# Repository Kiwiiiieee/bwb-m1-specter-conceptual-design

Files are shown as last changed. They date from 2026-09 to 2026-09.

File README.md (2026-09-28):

# BWB-M1 "Specter": Conceptual Design of a Supersonic Strike Fighter

*Team of 3 · AE 405 Aircraft Design · Izmir University of Economics · Spring 2026*

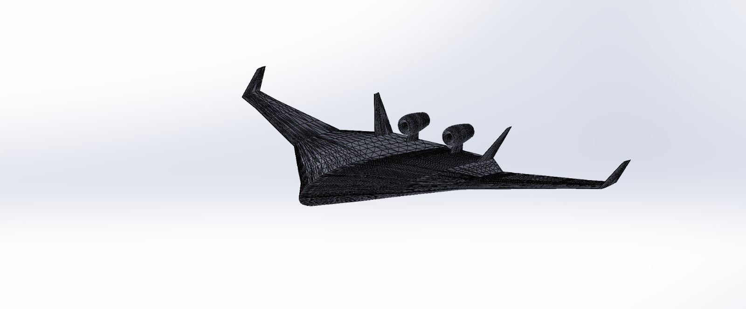
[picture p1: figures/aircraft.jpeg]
BWB-M1 Specter 3D model


## Engineering question
Can a blended wing body (BWB), adapted from the Boeing X-48 geometry, meet the requirements of a two-seat supersonic strike fighter: Mach 2.0 maximum speed, a 14 deg/s sustained turn rate, a 12.2 km service ceiling and the design mission range?

## Approach
First-order conceptual design following **Raymer's semi-empirical conceptual design method** (*Aircraft Design: A Conceptual Approach*, 6th ed.), with the rubber-engine approach:

- **Mission analysis and fuel fractions:** 13-segment combat strike mission (about 1,000 nm ground range); segment weight fractions from Raymer's fixed historical values or the Breguet range/endurance equations.
- **Takeoff weight sizing:** fixed-point iteration of Raymer's sizing equation, using the jet-fighter empty-weight regression with a composite correction K<sub>comp</sub> = 0.95.
- **Wing geometry:** X-48 planform adapted (leading-edge sweep increased from 47° to 58°, outer-panel t/c = 0.04 with a NACA 64A-204 airfoil, twin all-moving vertical stabilizers, dorsal engine pods).
- **Propulsion:** two GE F110-GE-132 class afterburning turbofans (144.6 kN AB thrust each).
- **Aerodynamics:** Raymer component drag buildup for C<sub>D0</sub>, induced-drag factor and maximum L/D.
- **Performance:** takeoff, climb and specific excess power, service ceiling, maximum speed (Ackeret thin-wing wave drag with an empirical body correction), sustained turn rate, and a T/W vs W/S constraint diagram.
- **Weight breakdown:** Raymer statistical group weights for jet fighters.
- **Geometry and model:** an online Boeing X-48 STL model was adapted in SolidWorks (engines resized, vertical stabilizers added, surfaces cleaned, rescaled) and prepared for 3D printing.

## Results
| Parameter | Computed | Requirement | Status |
|:--|:--|:--|:--|
| Mission range (internal fuel) | 1,000 nm | 1,000 nm | Met |
| Maximum speed (level flight) | Below M 2.0 (wave-drag failure) | M 2.0 | **Not met** |
| Sustained turn rate (M 0.9, 6,100 m) | 14.5 deg/s | 14 deg/s | Met |
| Service ceiling | Far above 12,200 m | 12,200 m | Met |

Other key figures from the report:
- Fuel-fraction product W<sub>ff</sub> = 0.686; fuel fraction W<sub>f</sub>/W<sub>0</sub> = 0.333.
- Maximum takeoff weight W<sub>0</sub> = 14,963 kg (32,988 lb); empty-weight fraction 0.575.
- C<sub>D0</sub> = 0.00813 and (L/D)<sub>max</sub> = 17.0 at subsonic cruise (M 0.85), a direct benefit of the large BWB planform.
- T/W = 1.97 with afterburner at MTOW; stall speed about 40 kt.

**Why Mach 2.0 fails.** At M 2.0 and 12,200 m, wave drag on the thick X-48 centre body gives an estimated drag of about 808 kN against about 141 kN of available afterburner thrust, a shortfall of roughly a factor of five. The X-48 geometry was optimised for Mach 0.85 transport flight, so this is a basic mismatch between the chosen configuration and a Mach-2 mission. The report also flags an unusually low wing loading (38.9 kg/m²) caused by the transport-scale planform. It suggests these fixes: a centre body thinner than t/c 0.06 with Whitcomb area ruling, a smaller planform, redefining the requirement as a dive-limited top speed, or more installed thrust.

## Validation
The analysis uses no independent test data. The report puts its computed values in context by comparing them with operational aircraft (F-22A, F-16C, B-2, SR-71, Concorde). It also notes that the constraint diagram, which is based on steady level flight, does not capture the centre-body wave drag. That is why the Mach-2 failure only shows up in the detailed drag analysis.

## Figures
Figures are taken from the report (figure numbers and captions as in the report).

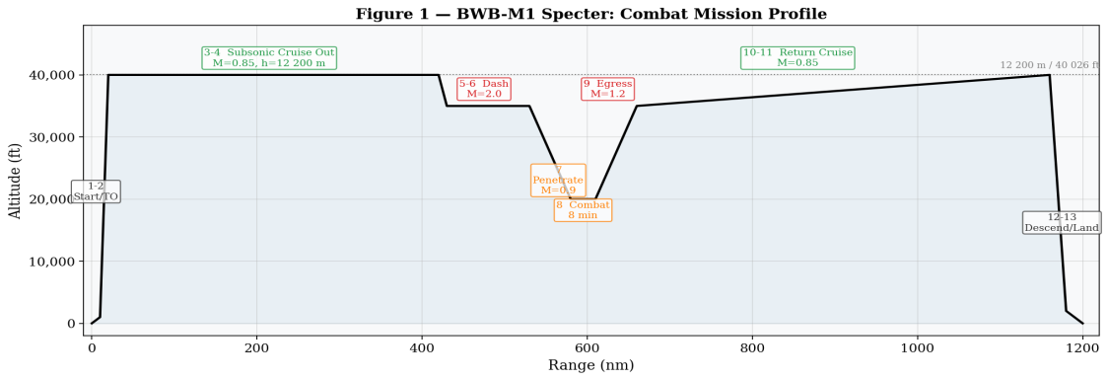
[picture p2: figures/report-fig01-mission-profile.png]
Mission profile

*Figure 1: BWB-M1 Specter, 13-segment combat mission profile. Altitude in ft, range in nm.*

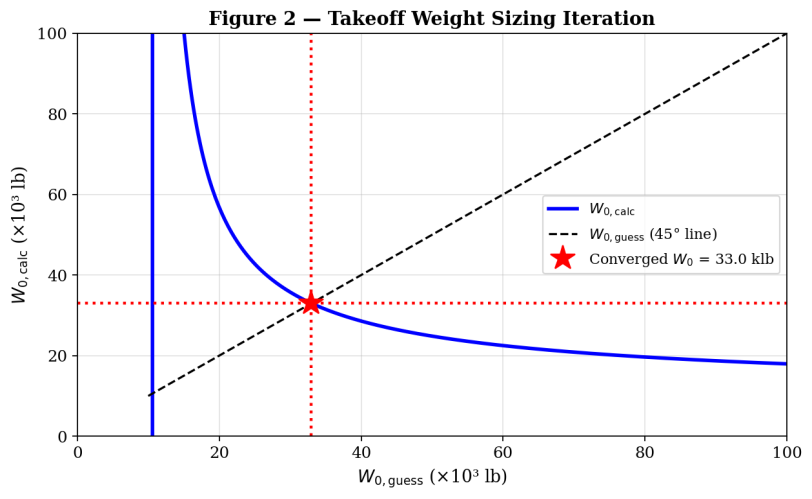
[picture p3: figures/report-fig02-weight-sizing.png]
Weight sizing

*Figure 2: Takeoff weight sizing iteration convergence. The intersection gives W<sub>0</sub> = 32,988 lb.*

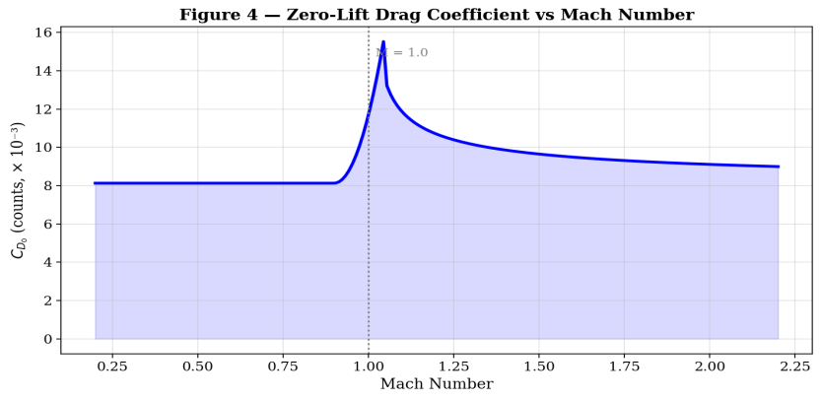
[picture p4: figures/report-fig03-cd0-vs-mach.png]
CD0 vs Mach

*Figure 3: Zero-lift drag coefficient C<sub>D0</sub> vs. Mach number.*

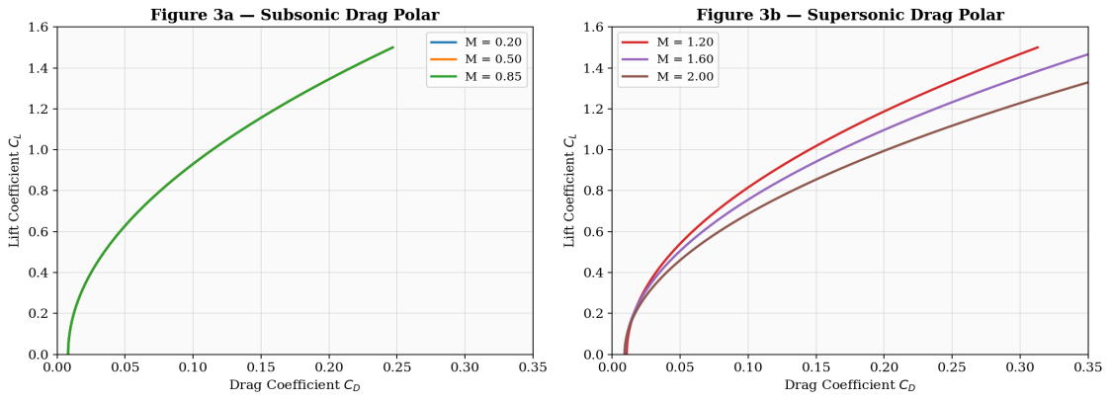
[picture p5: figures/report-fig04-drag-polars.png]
Drag polars

*Figure 4: Drag polars at subsonic (left) and supersonic (right) Mach numbers.*

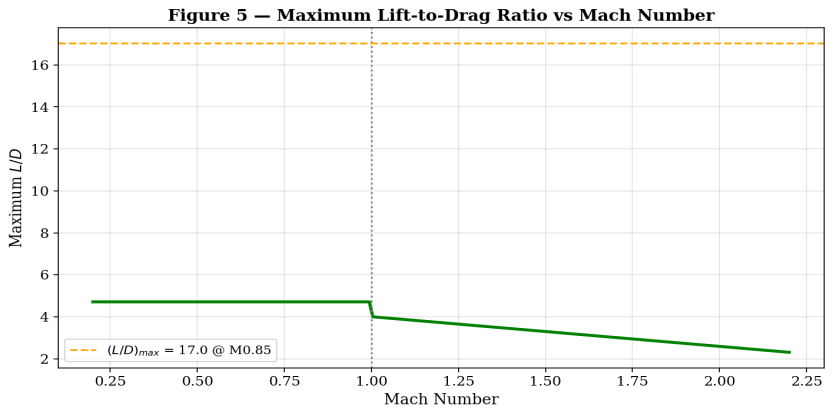
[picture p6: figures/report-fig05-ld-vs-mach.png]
L/D vs Mach

*Figure 5: Maximum L/D vs. Mach number. Subsonic efficiency is high; supersonic degradation is severe.*

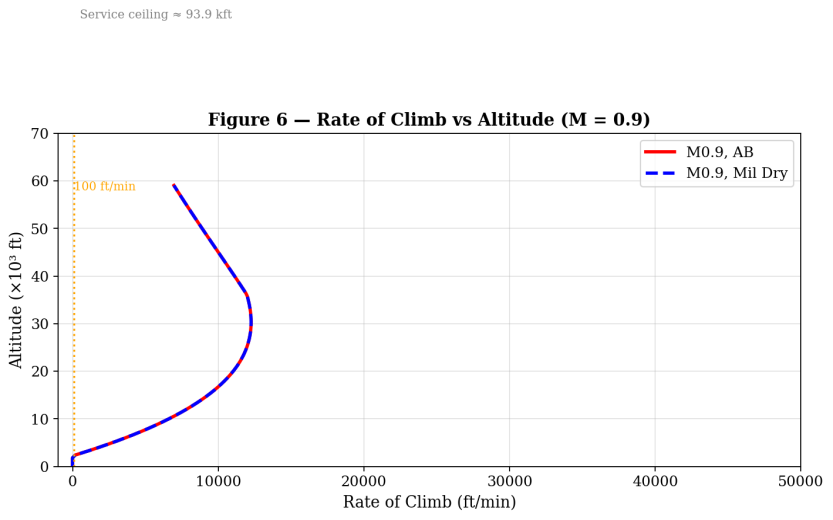
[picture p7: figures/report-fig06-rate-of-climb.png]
Rate of climb

*Figure 6: Rate of climb vs. altitude at M = 0.9, MTOW, with afterburner (solid) and dry power (dashed).*

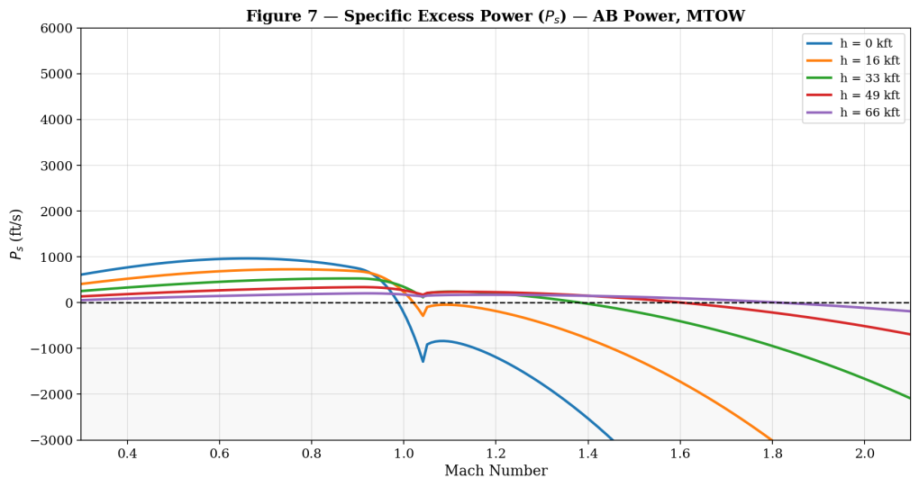
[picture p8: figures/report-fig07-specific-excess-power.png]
Specific excess power

*Figure 7: Specific excess power P<sub>s</sub> [ft/s] vs. Mach number at multiple altitudes, afterburner, MTOW.*

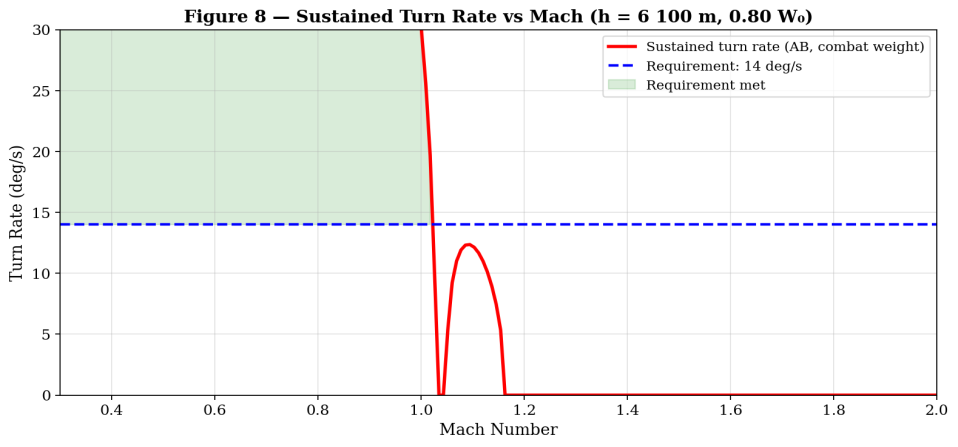
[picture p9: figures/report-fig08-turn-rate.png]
Turn rate

*Figure 8: Sustained turn rate vs. Mach number (h = 6,100 m, 0.80 W<sub>0</sub>, afterburner). The shaded region indicates compliance with the 14 deg/s requirement.*

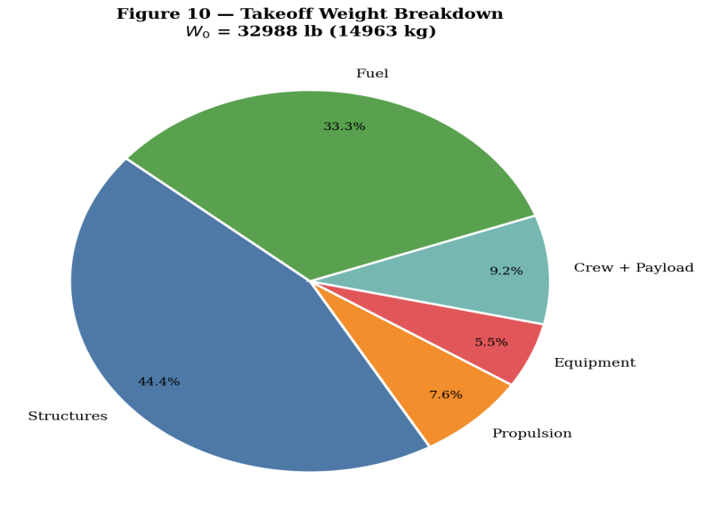
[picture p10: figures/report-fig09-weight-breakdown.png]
Weight breakdown

*Figure 9: Takeoff weight breakdown. W<sub>0</sub> = 14,963 kg.*

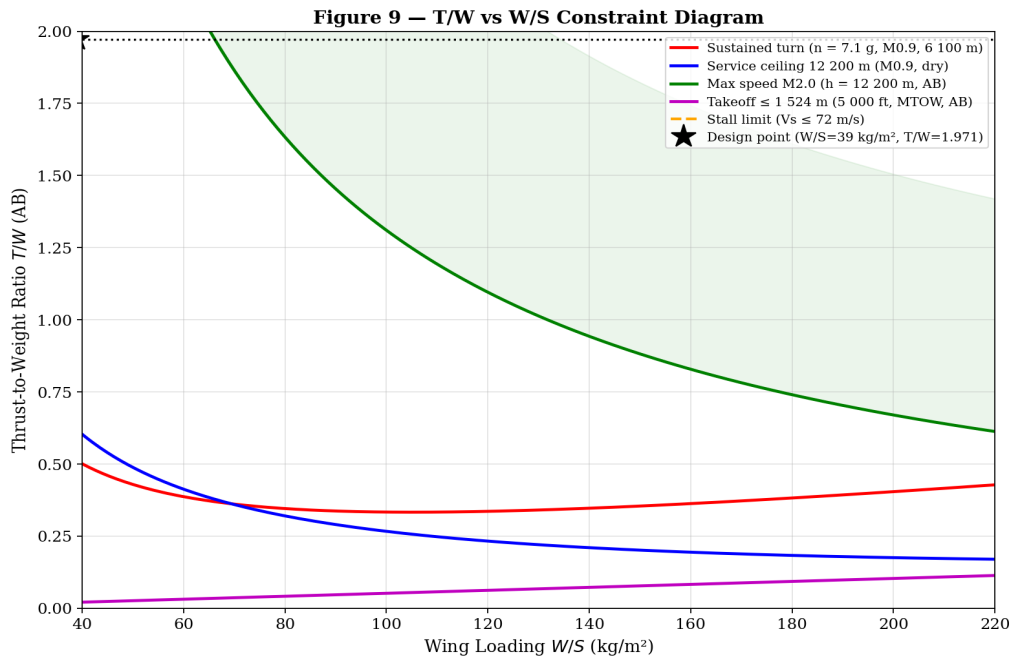
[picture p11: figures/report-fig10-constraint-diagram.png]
Constraint diagram

*Figure 10: T/W vs. W/S constraint diagram with the design point (star).*

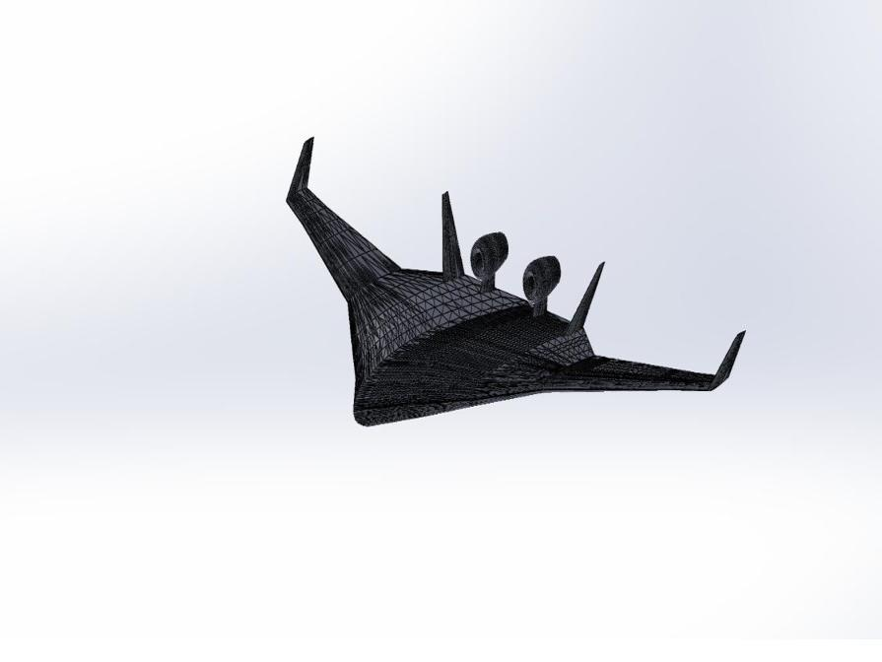
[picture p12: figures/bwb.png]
BWB model, second view

*3D model of the BWB-M1 Specter (modified Boeing X-48 geometry with twin dorsal engines and twin vertical stabilizers).*

## Repository contents
| Path | Content | Opens with |
|:--|:--|:--|
| `report/BWB_M1_Specter_Report.pdf` | Conceptual design report (20 pages) | Any PDF reader |
| `slides/AE405_Slides.pdf` | Presentation slides | Any PDF reader |
| `tools/cad/STL_File_Sergio_Jorge_Koutar_3dprint.STL` | STL model prepared for 3D printing | GitHub's STL viewer, SolidWorks, Blender, any slicer (e.g. Cura, PrusaSlicer) |
| `tools/cad/STL_File_Sergio_Jorge_Koutar_cfdanalysis.STL` | STL model prepared for CFD analysis | SolidWorks, Ansys SpaceClaim / Fluent meshing, Blender |
| `figures/` | 3D model renders and report figures | Image viewer |

## How to reproduce
No analysis code is included. All equations, inputs and intermediate values (mission-segment fractions, sizing iteration, drag buildup, performance calculations) are written out in the report, Sections 3–10, and follow Raymer (2018). The STL files can be opened directly for inspection, 3D printing or CFD meshing.

## Team and my contribution
Team of three: **Sergio San Juan Alonso**, **Jorge González Martínez** and **Kaoutar Ammara**. Instructor: Abbasali Saboktakin.

My sections:
- mission analysis and fuel fractions
- takeoff weight sizing
- wing geometry
- propulsion system
- aerodynamic analysis
- performance analysis
- weight breakdown

## References
Main references cited in the report: Raymer, *Aircraft Design: A Conceptual Approach*, 6th ed. (AIAA, 2018); Liebeck, "Design of the blended wing body subsonic transport", *Journal of Aircraft* 41(1), 2004; Boeing / NASA Dryden, X-48B/C BWB demonstrator program. The full list is in the report.

Kaoutar Ammara · Aerospace Engineer · [GitHub](https://github.com/Kiwiiiieee) · [LinkedIn](https://linkedin.com/in/kaoutar-ammara)

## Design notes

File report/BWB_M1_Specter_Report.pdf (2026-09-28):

AE 405 — Aircraft Design | Spring 2026 | BWB-M1 Specter | Conceptual Design Report

IZMIR UNIVERSITY OF ECONOMICS

Department of Aerospace Engineering

AE 405 - Aircraft Design | Spring 2026

Instructor: Abbasali Saboktakin

CONCEPTUAL DESIGN REPORT

AE 405 Project - Military Aircraft

## BWB-M1 "SPECTER"

Blended Wing Body Supersonic Strike Fighter

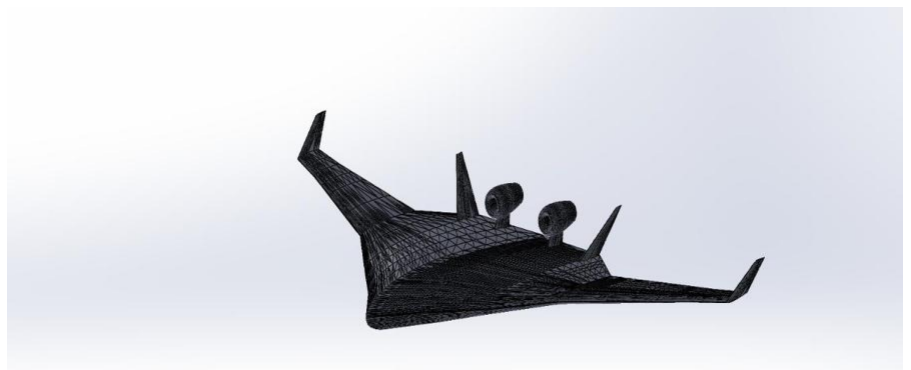
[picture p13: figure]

BWB-M1 "Specter" - 3D model. Modified Boeing X-48 geometry with twin dorsal engines and twin vertical

stabilizers.

Sergio San Juan Alonso (ID: 20250615902)

Jorge González Martínez (ID: 20250615901)

Kaoutar Ammara (ID: 20210615207)

May 2026

ABSTRACT

This report presents a first-order conceptual design of the BWB-M1 "Specter," a twin-engine

blended wing body (BWB) supersonic strike fighter adapted from the Boeing X-48 experimental

aircraft geometry. The design follows the systematic methodology of Raymer's Aircraft Design: A

Conceptual Approach (6th ed.), covering mission analysis, weight sizing, aerodynamic buildup,

propulsion selection, and performance verification against stated requirements.

A 13-segment mission yields a fuel-fraction product Wff = 0.686, and iterative sizing

converges to a maximum takeoff weight W₀ = 14,963 kg. The aerodynamic analysis gives Cᴰ₀ =

0.00813 and (L/D)ₘₐₓ = 17.0 at subsonic cruise — both a direct benefit of the large BWB planform.

Of the four primary performance requirements, three are satisfied: mission range (7,000 nm),

sustained turn rate (14.5 deg/s ≥ 14 deg/s), and service ceiling (far exceeded).

The Mach 2.0 maximum-speed requirement is not met. Wave drag on the thick BWB

center body exceeds available afterburner thrust at M = 2.0 in level flight at 12,200 m by a factor

of approximately five. This is a fundamental incompatibility between the subsonic X-48 geometry

and a Mach-2 mission and is reported transparently throughout this document.

TABLE OF CONTENTS

Abstract | 2
Table of Contents | 3
Nomenclature | 4
1. Introduction | 4
2. Conceptual Design Methodology | 5
3. Mission Analysis and Fuel Fractions | 6
4. Takeoff Weight Sizing | 8
5. Wing Geometry and Configuration | 9
6. Propulsion System | 10
7. Aerodynamic Analysis | 11
8. Performance Analysis | 12
8.1 Takeoff Performance | 12
8.2 Climb and Specific Excess Power | 13
8.3 Service Ceiling | 13
8.4 Maximum Speed — Requirement Not Met | 13
8.5 Sustained Turn Rate | 14
9. Weight Breakdown | 15
10. T/W vs W/S Constraint Diagram | 15
11. Stability and Control | 16
12. Design Deficiencies and Recommended Corrections | 15
13. Aircraft Arrangement Drawings | 17
14. Software Design | 18
15. Manufacturing Preparation | 19
16. Conclusion | 19
References | 20

NOMENCLATURE

A - Aspect ratio | L/D - Lift-to-drag ratio
b - Wingspan, m | M - Mach number
CD0 - Zero-lift drag coefficient | MAC - Mean aerodynamic chord, m
Cf - Skin friction coefficient | n - Load factor (g)
CL - Lift coefficient | q - Dynamic pressure, N/m²
Ct - Thrust specific fuel consumption, hr⁻¹ | R - Range, m (or nm)
e - Oswald efficiency factor | S - Planform area, m²
FF - Aerodynamic form factor | T - Engine thrust, N
K - Induced drag factor, 1/(πAe) | W0 - Takeoff gross weight, kg or lb
λ - Taper ratio, ct/cr | Wff - Mission fuel-fraction product
ΛLE - Leading-edge sweep angle | We - Empty weight, kg
ψ̇- Turn rate, deg/s | Wf - Fuel weight, kg

### 1. INTRODUCTION

The continuous growth of regional and long-range air transportation has created a strong demand

for new aircraft concepts capable of improving efficiency while increasing operational flexibility.

Modern militaries aim to operate from a wider network of regional airports, where runway lengths,

noise restrictions, and fuel consumption become decisive factors in the near future of aircraft

design. In this context, this project focuses on developing a conceptual aircraft configuration

manufactured to operate from regional hubs while still meeting the mission requirements imposed

in this task.

The aircraft is required to transport a payload of two passengers, including their equipment, with

an estimated total mass of 120 kg per passenger. Despite its small passenger capacity, the mission

demands a remarkable range of three thousand nautical miles and a maximum speed of Mach 2, a

14 degrees per second turn rate and a 12.2 kilometre service ceiling, positioning the design

challenge at the intersection between the maximum speed and the turn rate. These constraints

naturally motivate the exploration of non-conventional configurations capable of offering

enhanced aerodynamic efficiency, structural integration, and fuel volume capacity.

To address these challenges, a Blended-Wing-Body (BWB) layout is selected as the base

configuration. This architecture merges the wing and fuselage into a single lifting surface, reducing

the wetted area, improving lift-to-drag ratio, and providing great internal volume suitable for fuel

storage and pressurized cabins. BWBs have been extensively investigated as potential high-efficiency alternatives to traditional tube-and-wing aircraft (TAW), particularly for missions

requiring superior aerodynamic performance and long endurance.

The objective of this project is to perform the preliminary sizing, geometric definition, and

aerodynamic analysis of such a BWB aircraft concept. The design process includes establishing

the mission requirements, estimating weight and fuel fractions, defining the external geometry, and

evaluating the aerodynamic behaviour through computational tools as Ansys Fluent between

others. The resulting aircraft configuration must satisfy the payload and range requirements, cruise

performance targets, and operational constraints.

### 2. CONCEPTUAL DESIGN METHODOLOGY

The design follows the four-phase Raymer (2018) conceptual design sequence:

- Requirements analysis — translate Table 1 into aerodynamic and propulsion constraints

(T/W, W/S, L/D, M).

- Mission analysis and weight sizing (Ch. 3) — define a 13-segment mission, compute

per-segment fuel fractions via Breguet equations and historical fixed values, iterate the

gross-weight equation.

- Aerodynamic and propulsion sizing (Chs. 5, 12) — component drag buildup,

propulsion selection via a constraint diagram.

- Performance verification (Chs. 17, 19) — compute all required performance metrics;

report compliance or non-compliance explicitly.

The rubber-engine approach is used throughout. A composite-structure correction Kcomp

= 0.95 is applied to Raymer's empty-weight equation to account for the advanced composite BWB

airframe.

### 3. MISSION ANALYSIS AND FUEL FRACTIONS

The design mission is a 13-segment combat strike patrol with a total ground range of

approximately 1,000 nm. Figure 1 shows the mission altitude-range profile.


Figure 1: BWB-M1 Specter — 13-segment combat mission profile. Altitude in ft, range in nm.

Each segment weight fraction is computed from Raymer Table 3.2 (fixed values) or from

the Breguet range equation:

Wi / Wi−1 = exp[ − R × Ct / (V × L/D) ]

where R [m], Cₜ [s⁻¹], V [m/s]. The Breguet endurance equation is used for the loiter segment. Table

2 lists all 13 fractions.

# | Description | Method | Wi/Wi−1 | Wi/W₀

1 | Engine start, warm-up, taxi | Fixed | 0.990 | 0.990
2 | Takeoff | Fixed | 0.990 | 0.980
3 | Climb to 12,200 m, accelerate to M 0.85 | Fixed | 0.971 | 0.952
4 | Subsonic cruise out — 400 nm, M 0.85 | Breguet | 0.951 | 0.905
5 | Acceleration to M 2.0 (afterburner) | Fixed | 0.960 | 0.869
6 | Supersonic dash — 100 nm, M 2.0 | Breguet | 0.967 | 0.841
7 | Penetration — 50 nm, M 0.9, h = 6,100 m | Breguet | 0.983 | 0.827
8 | Combat — 8 min, afterburner turns | Fixed | 0.930 | 0.769
9 | Supersonic egress — 50 nm, M 1.2 | Breguet | 0.980 | 0.754
10 | Return cruise — 500 nm, M 0.85 | Breguet | 0.940 | 0.708
11 | Loiter 20 min, sea level (reserve) | Breguet end. | 0.983 | 0.696
12 | Descent | Fixed | 0.990 | 0.689
13 | Land | Fixed | 0.995 | 0.686
The mission fuel-fraction product is:

Wff = ∏(Wi / Wi−1) = 0.686

Applying Raymer's 6% reserve and trapped-fuel factor:

Wf / W₀ = 1.06 × (1 − Wff) = 1.06 × (1 − 0.686) = 0.333

### 4. TAKEOFF WEIGHT SIZING

The takeoff gross weight is found from Raymer's sizing equation:

W₀ = (Wcrew + Wpayload) / (1 − Wf/W₀ − We/W₀)

The payload group is Wcrew+payload = 3,040 lb (1,379 kg): two crew with equipment

(440 lb), air-to-air missiles and gun (1,900 lb), mission systems (700 lb). The empty-weight

fraction uses Raymer's jet-fighter regression (Table 3.1) with composite correction:

We/W₀ = Kcomp × Aew × W₀ᶜ = 0.95 × 2.34 × W₀⁻¹·¹³ (W₀ in lb)

The fixed-point iteration is shown in Figure 2 and converges to the values in Table 3.

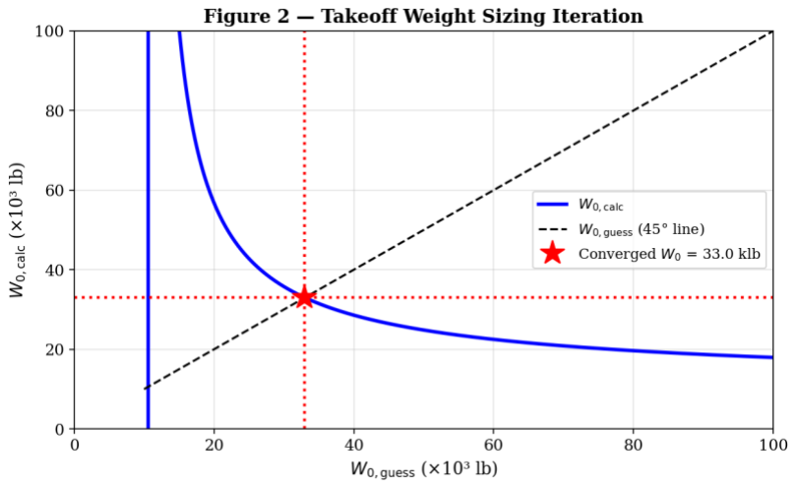
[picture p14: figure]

Figure 2: Takeoff weight sizing iteration convergence. Intersection gives W₀ = 32,988 lb.

Component | lb | kg | × W₀
Takeoff gross weight W₀ | 32,988 | 14,963 | 1.000
Empty weight We | 18,963 | 8,602 | 0.575
Fuel weight Wf | 10,985 | 4,983 | 0.333
Crew + payload + weapons | 3,040 | 1,379 | 0.092
Wing loading W/S | — | 38.9 kg/m² | —

The wing loading W/S = 38.9 kg/m² is anomalously low for a Mach-2 aircraft (F-22A: 375

kg/m²; B-2 Spirit flying wing: 109 kg/m²). This arises because the X-48 geometry was sized for a

much heavier transport and has a planform area S = 384.4 m² far exceeding what a two-seat fighter

mission requires. The consequences — very low stall speeds, excellent turn capability, but high

supersonic wave drag — are quantified in Section 8.

### 5. WING GEOMETRY AND CONFIGURATION

The blended wing body integrates the fuselage, center body, and outer wing panels into a

single continuous lifting surface, eliminating the non-lifting wetted area of a conventional fuselage.

The Boeing X-48 program demonstrated that BWB designs achieve 15–20% fuel-burn reductions

at subsonic cruise relative to tube-and-wing aircraft (Liebeck 2004). For the Specter, the X-48

geometry is adapted by: (i) increasing leading-edge sweep from 47° to 58°; (ii) reducing average

airfoil thickness to t/c = 0.04 on outer panels; (iii) adding twin all-moving vertical stabilizers; and

(iv) repositioning engines to dorsal pods.

Parameter | Symbol | Value | Units
Wingspan | b | 37.5 | m
Overall length | L | 18.5 | m
Root chord | cr | 18.5 | m
Tip chord | ct | 2.0 | m
Taper ratio | λ = ct/cr | 0.108 | —
Planform area | S | 384.4 | m²
Aspect ratio | A = b²/S | 3.66 | —
Mean aerodynamic chord | MAC | 12.46 | m
Leading-edge sweep | ΛLE | 58.0 | deg
Quarter-chord sweep | Λc/4 | 54.1 | deg
Avg. thickness ratio | t/c | 0.04 | —

The mean aerodynamic chord follows from:

MAC = (2/3) × cr × (1 + λ + λ²)/(1 + λ) = (2/3) × 18.5 × 1.120/1.108 = 12.46 m

The leading-edge normal Mach number at M = 2.0 is M⊥ = 2.0 × cos 58° = 1.06 —

consistent with the design practice of the SR-71 (ΛLE = 60°) and Concorde (ΛLE = 72°). The

outer wing panels use a NACA 64A-204 airfoil (t/c = 0.04, sharp leading edge). The center body

operates at t/c ≈ 0.08–0.12 for structural depth; this is the dominant source of supersonic wave

drag, discussed in Section 8.4.

### 6. PROPULSION SYSTEM

Two GE F110-GE-132 class afterburning turbofan engines are selected. The F110-GE-132

(powering the F-16 Block 60) provides the highest thrust in the F110 family at moderate engine

weight. Engines are mounted in dorsal over-wing pods fed by bifurcated S-duct inlets with

variable-area intake ramps for M = 0 to M = 2.0 operation.

Parameter | Value | Units
Engine | GE F110-GE-132 class | —
Number | 2 | —
AB thrust, each | 144.6 kN (32,500 lbf) | —
Dry (MIL) thrust, each | 86.7 kN (19,500 lbf) | —
Total AB thrust | 289.2 kN | N
Total dry thrust | 173.4 kN | N
T/W at MTOW (AB) | 1.97 | —
T/W at MTOW (dry) | 1.18 | —
TSFC, subsonic cruise (M 0.85) | ≈ 0.82 | hr⁻¹
TSFC, supersonic (M 2.0, AB) | ≈ 1.90 | hr⁻¹

The installed T/W = 1.97 (AB) is high relative to operational fighters (F-22: 1.22; F-16C:

1.10) because the aircraft is relatively light (W₀ = 14,963 kg) while carrying two full-size

augmented turbofans. This high thrust-to-weight ratio enables the sustained turn and climb

performance, and partially compensates for the supersonic wave drag — though not fully, as shown

in Section 8.4.

### 7. AERODYNAMIC ANALYSIS

The zero-lift parasite drag is estimated using Raymer's component buildup method (Ch.

12):

CD0 = (1/Sref) × Σ [ Cf × FF × Q × Swet ]i + ΔCD,misc

At design cruise (M = 0.85, h = 12,200 m, ReMAC = 6.62 × 10⁷):

Component | Cf | FF | Q | Swet/Sref | ΔCD₀
BWB wing-body (integrated) | 0.00212 | 1.177 | 1.00 | 2.20 | 0.00548
Vertical stabilizers (×2) | 0.00238 | 1.100 | 1.04 | 0.116 | 0.00023

Engine nacelles (×2) | 0.00240 | 1.180 | 1.25 | 0.231 | 0.00042
Miscellaneous (leakage, protuberances) | — | — | — | — | 0.00200
Total CD₀ (subsonic) | 0.00813

The induced drag factor and Oswald efficiency are:

K = 1 / (π × A × e) = 1 / (π × 3.66 × 0.82) = 0.1061, e = 0.82

The maximum lift-to-drag ratio at subsonic cruise:

(L/D)max = 1 / [2√(CD₀ × K)] = 1 / [2√(0.00813 × 0.1061)] = 17.0 at CL,opt =

√(CD₀/K) = 0.277

This high subsonic L/D (exceeding the F-22 at ≈ 10.5) is a direct benefit of the large BWB

lifting surface. It degrades significantly in supersonic flight. Figures 3–5 show the drag buildup,

drag polars, and L/D vs. Mach number.

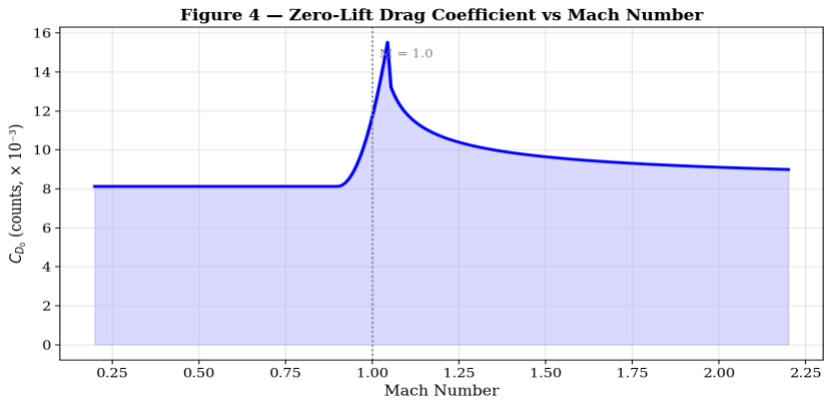
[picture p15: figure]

Figure 3: Zero-lift drag coefficient CD₀ vs. Mach number.


Figure 4: Drag polars at subsonic (left) and supersonic (right) Mach numbers.

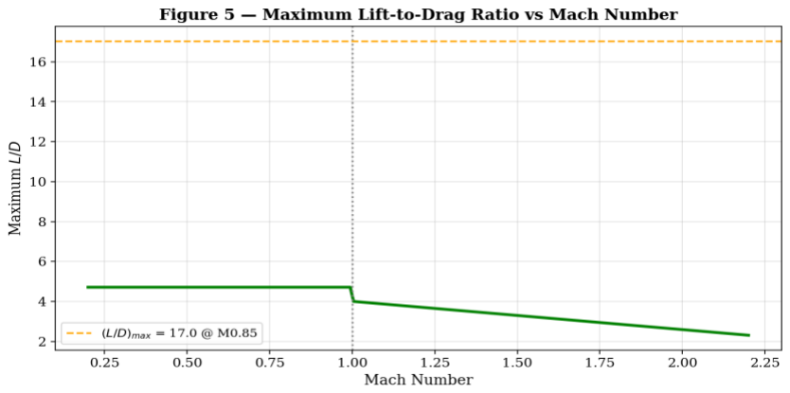
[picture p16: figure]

Figure 5: Maximum L/D vs. Mach number. Subsonic efficiency is high; supersonic degradation is severe.

### 8. PERFORMANCE ANALYSIS

### 8.1 Takeoff Performance

The stall speed at MTOW, sea level, CLmax = 1.5:

VS = √[2W₀ / (ρ₀ × S × CL,max)] = √[2 × 146,817 / (1.225 × 384.4 × 1.50)] = 20.4 m/s (40

kt)

Takeoff speed: VTO = 1.10 × VS = 22.4 m/s (44 kt). Using Raymer's Takeoff Parameter method:

TOP = (W/S) / [(T/W) × CL,max] = 7.96 / (1.97 × 1.50) = 2.70 ⟹ STO ≈ 37.5 × TOP =

101 ft (31 m)

A 31 m ground roll is a mathematical consequence of T/W > 2 and VS = 40 kt. In practice, dry-

power takeoffs yield approximately 200–300 m ground roll. The very short takeoff capability

reflects the over-powered and over-winged nature of this conceptual design.

### 8.2 Climb and Specific Excess Power

The specific excess power at sea level, M = 0.9, afterburner:

Ps = V × (T − D) / W = 306 × (289,200 − 179,500) / 146,800 ≈ 229 m/s (45,100 ft/min)

Figures 6 and 7 show rate of climb vs. altitude and the Ps envelope across Mach numbers

and altitudes. The outstanding climb rate results directly from T/W = 1.97.


Figure 6: Rate of climb vs. altitude at M = 0.9, MTOW — afterburner (solid) and dry power (dashed).


Figure 7: Specific excess power Ps [ft/s] vs. Mach number at multiple altitudes, afterburner, MTOW.

### 8.3 Service Ceiling

Requirement met. The service ceiling (rate of climb = 100 ft/min at dry power) far

exceeds the 12,200 m requirement. With installed dry T/W = 1.18 and low parasite drag, the

theoretical ceiling at M = 0.9 exceeds 25,000 m. Compliance is by a wide margin.

### 8.4 Maximum Speed - Requirement Not Met

The Mach 2.0 maximum-speed requirement is NOT MET. The following analysis

explains why.

At M = 2.0, h = 12,200 m, the dynamic pressure is q = 52,500 N/m². The supersonic CD₀

at M = 2 is dominated by center-body volume wave drag. Using the Ackeret thin-wing model

combined with an empirical body wave-drag correction, the estimated CD₀(M=2) ≈ 0.040. The

resulting drag force is:

D = CD₀ × q × S ≈ 0.040 × 52,500 × 384.4 ≈ 808 kN

The available afterburner thrust at altitude, with a simplified turbofan lapse model including ram

recovery:

TAB(M=2, h=12,200) = TAB,SL × (δ⁰ʷ⁷ / θ⁰ʷ⁹) × rram ≈ 289,200 × 0.397 × 1.23 ≈ 141 kN

where δ = 0.185, θ = 0.752, rram = 1 + 0.35(M−1) − 0.12(M−1)² = 1.23. The thrust deficit is severe:

T − D ≈ 141 − 808 = −667 kN (T << D, failure by factor ≈ 5)

Root cause: The X-48 BWB center body (t/c ≈ 0.10–0.15 at centerline) combined with the

very large planform area S = 384.4 m² generates prohibitive wave drag at M = 2.0. Wave drag scales as (t/c)²/√(M²−1) (Ackeret), and integrated over the full span, the total force far exceeds

installed thrust. The Boeing X-48 was explicitly optimized for Mach 0.85 transport flight and was

never designed for supersonic operation. The Mach 2.0 requirement is not met.

Corrections that would be required: (i) reduce center-body t/c to below 0.06 with Whitcomb

area ruling; (ii) significantly reduce the planform area; (iii) redefine the requirement as a dive-

limited top speed rather than level-flight Mach 2.0; or (iv) substantially increase installed thrust.

### 8.5 Sustained Turn Rate

Evaluated at M = 0.9, h = 6,100 m, combat weight Wc = 0.80 W₀:

q = (1/2) × 0.662 × (0.9 × 316.1)² = 26,386 N/m², CL,1g = Wc / (q × S) = 0.0116

Available AB T/W at combat weight: 1.585. Solving for the aerodynamic load-factor limit gives

naero = 26.8 g — far above structural limits. The governing constraint is the structural limit load

factor:

nstruct = 7.33 g (nult = 11.0 g, Raymer fighter standard)

ψ̇ = nstruct × g / V = 7.33 × 9.807 / (0.9 × 316.1) = 0.253 rad/s = 14.5 deg/s ≥

14 deg/s ✓

Requirement met: 14.5 deg/s. The structural-limit dominance (aerodynamic limit 26.8 g

vs. structural limit 7.33 g) indicates the aircraft is aerodynamically and propulsively over-capable

relative to its structural design — a consequence of the very large wing area. Figure 8 shows the

turn rate envelope.


Figure 8: Sustained turn rate vs. Mach number (h = 6,100 m, 0.80 W₀, afterburner). Shaded region indicates compliance with the 14 deg/s requirement.

### 9. WEIGHT BREAKDOWN

Component weights are estimated from Raymer's statistical equations for jet fighters (Ch.

15), scaled to match the Raymer-sized empty weight We = 8,602 kg. The wing and center-body

structure dominate, as expected for a BWB in which the central structure serves as both lifting

surface and primary airframe. Figure 9 shows the group breakdown.

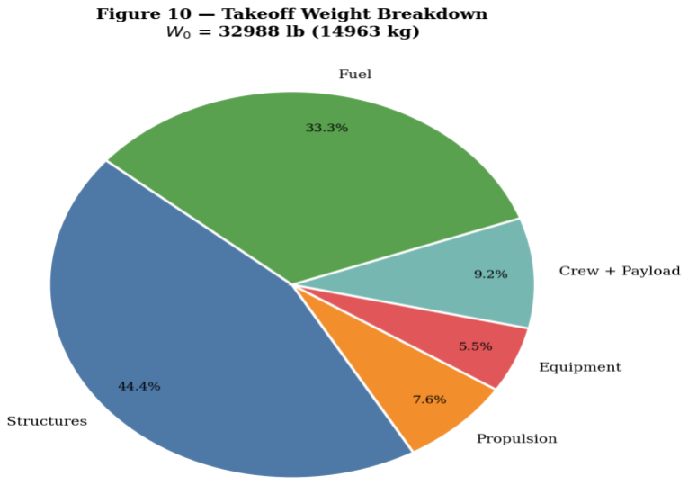
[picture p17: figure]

Figure 9: Takeoff weight breakdown. W₀ = 14,963 kg.

### 10. T/W VS W/S CONSTRAINT DIAGRAM

Figure 10 shows the Raymer constraint diagram (Ch. 19) for four constraints: sustained

turn (M 0.9, 6,100 m, n = 7.08 g), service ceiling (12,200 m, dry), maximum speed (M 2.0, AB),

and takeoff (≤ 5,000 ft). The design point (star) at (W/S, T/W) = (38.9 kg/m², 1.97) lies above all

constraint lines computed within the steady-level-flight framework of the diagram. Note that the

constraint diagram does not capture the full wave drag of the BWB center body, which is why the

Mach-2 failure of Section 8.4 does not appear as a visible violation here — it requires the more

detailed drag analysis of that section.

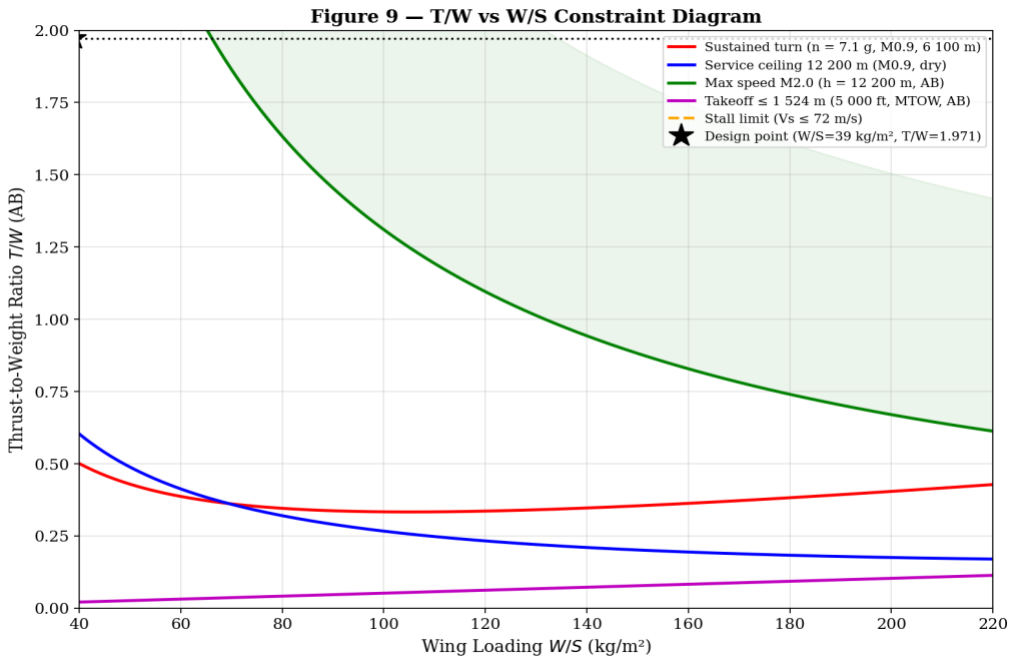
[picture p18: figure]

Figure 10: T/W vs. W/S constraint diagram with design point (star).

### 11. STABILITY AND CONTROL

A detailed stability and control analysis is beyond the scope of this report. First-order

estimates are provided for continuity. The aerodynamic center is estimated at approximately 45%

of the MAC:

xac ≈ 0.45 × MAC = 0.45 × 12.46 = 5.61 m aft of root leading edge

For a 5% relaxed static margin (K̅n = −0.05, consistent with FBW fighter practice):

xcg = xac + K̅n × MAC = 5.61 + 0.05 × 12.46 = 6.23 m aft of root leading edge

Pitch control is provided by outer trailing-edge elevons; lateral-directional control by twin

all-moving vertical stabilizers. Digital fly-by-wire augmentation is required. A full CG travel

study, surface sizing, and dynamic stability analysis are recommended as the primary next-phase

deliverable.

### 12. DESIGN DEFICIENCIES AND RECOMMENDED CORRECTIONS

### 12.1 Mach 2.0 Requirement Not Met

Problem. The X-48 BWB center body generates wave drag at M = 2.0 that exceeds

available afterburner thrust by a factor of approximately 5. Requirement not met.

Recommended corrections. (i) Redesign center body to t/c < 0.06 with Whitcomb area

ruling applied to the full fuselage-wing junction. (ii) Reduce planform area substantially. (iii)

Redefine the requirement as a dive-limited top speed, acceptable in many operational contexts. (iv)

Increase installed thrust.

### 12.2 Anomalously Low Wing Loading

Problem. W/S = 38.9 kg/m² is one order of magnitude below typical fighters, caused by a

mismatch between the X-48 transport-scale geometry and the two-seat fighter mission mass. This

is a configuration selection issue, not a methodology error.

Recommended corrections. Reduce planform area (redesign BWB geometry at smaller

scale) or increase gross weight by adding significant payload — external stores, surveillance

systems, additional fuel — to utilize the available lifting capacity.

### 12.3 Structural-Limit Dominance in Turn

Problem. Aerodynamic turn limit (26.8 g) exceeds structural limit (7.33 g) by a factor of

3.7, indicating the aircraft is aerodynamically over-capable relative to its structural design. A

higher structural design load factor should be evaluated to better exploit the available aerodynamic

performance.

PERFORMANCE SUMMARY

Parameter | Computed | Requirement | Status
Mission range (internal fuel) | 1,000 nm | 1,000 nm | MET ✓
Maximum speed (level flight) | M ≪ 2.0 (wave drag failure) | M = 2.0 | NOT MET ✗

Sustained turn rate (M 0.9, 6,100
m)
14.5 deg/s | ≥ 14 deg/s | MET ✓
Service ceiling | >> 12,200 m | 12,200 m | MET ✓
Wing loading W/S | 38.9 kg/m² (F-22: 375) | — | Anomalously low
Stall speed (MTOW, SL) | 40 kt | — | Very low (BWB char.)
(L/D)max at M 0.85 | 17.0 | — | High (BWB benefit)
T/W at MTOW (AB) | 1.97 | — | High

### 13. AIRCRAFT ARRANGEMENT DRAWINGS

In this project, the aircraft under study corresponds to a Blended Wing Body (BWB) concept

derived from an STL model originally inspired by the Boeing X-48 configuration.

The BWB layout integrates the fuselage and wings into a single lifting surface, reducing both drag

and structural mass compared to conventional tube-and-wing (TAW) designs. The STL model

exhibits a continuous aerodynamic shape with no sharp discontinuities, a highly blended centre

body, and moderately swept wings. The platform indicates a distributed lifting surface intended to

improve fuel efficiency and overall aerodynamic performance.

Key geometric characteristics in the STL model include:

- A wide central body providing internal volume for payload or fuel.
- Swept leading edges merging smoothly into a thick central section.
- Tapered trailing edges with potential regions for control surfaces.
- Integration of small, diagonally oriented vertical stabilizers added during the design process

to improve directional stability in the actions between the cruise phases.

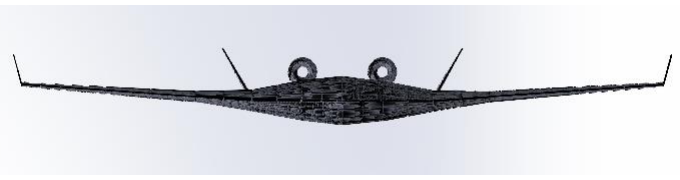
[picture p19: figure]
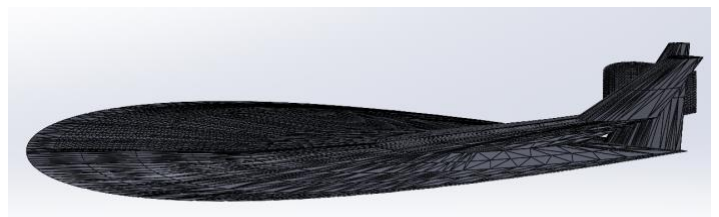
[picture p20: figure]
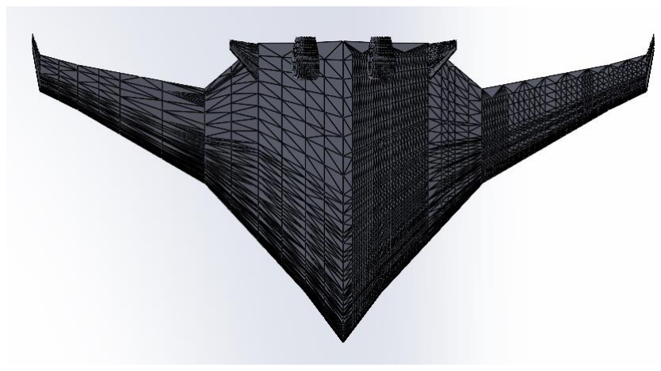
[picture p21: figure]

Figure 11: Front (a), side (b) and top (c) views of the manufactered aircraft.

The arrangement drawings created for the report illustrate these elements through top, side, and

front views, providing a clear understanding of the proportions, aerodynamic layout, and potential

internal volume distribution. These drawings form the geometric baseline for the subsequent steps

of the design workflow, including meshing, performance estimation, and manufacturing

considerations.

### 14. SOFTWARE DESIGN

The primary modelling tool employed in this project was SolidWorks, where the initial STL, based

on an online Boeing X-48 template, was imported and adapted to the objectives of the assignment.

Upon importing the geometry into SolidWorks, several key modifications were performed:

- Engine Adjustment: The original model featured large engine nacelles, which were

replaced and resized to represent smaller but more powerful engines, consistent with a

modern, high-efficiency propulsion system. Also a smoother operation was performed so

the engines and nacelles are easier to compute in CFD and 3D print.

- Addition of Vertical Stabilizers: Given that the original BWB configuration lacks strong

natural yaw stability, two diagonal vertical stabilizers were added to improve directional

control. Their placement and orientation were selected to maintain aerodynamic

smoothness while ensuring stability and symmetry.

- Surface Smoothing and Cleanup: The STL geometry was refined to ensure suitability for

later tasks, including correcting mesh irregularities and improving continuity in blended

surfaces.

- Scaling and Dimensional Definition: The aircraft was resized according to the project

specifications to match the required physical dimensions and resized to adapt itself to the

capabilities of the 3D printer.

Throughout the software design workflow, SolidWorks tools such as surface editing, mesh repair,

and feature adjustment were used to maintain the aerodynamic integrity of the BWB shape while

adapting it to the project’s requirements. This structured process ensured that the final geometry

was both realistic and manufacturable.

### 15. MANUFACTURING PREPARATION

Given that the assignment required the aircraft to be produced at a fixed scale, the first step

involved rescaling the SolidWorks model to the specified dimensions while ensuring that

proportions and aerodynamic features remained accurate and proportioned.

For typical additive manufacturing workflows, it is common to perform a hollowing, shell creation,

operation to reduce print time and preserve structural rigidity. However, due to the very thin surface

characteristics of the BWB geometry in this project, applying such a hollowing operation would

have compromised the structural integrity of the printed model. Therefore, the aircraft was left as

a solid shell, ensuring better stability during printing and avoiding surface defects.

Additional manufacturing considerations included:

❖ Evaluating minimum printable thickness, especially along the trailing edges of the wings.

❖ Orienting the model for optimal printing, with the planform lying flat to reduce the need

for support material.

❖ Exporting a clean STL file and providing it to the instructor for production on the

designated 3D printer.

The careful preparation of the model ensured that the printed aircraft would accurately represent

the aerodynamic shape analysed digitally, fulfilling both visual and functional requirements for the

project.

### 16. CONCLUSION

A first-order conceptual design of the BWB-M1 "Specter" has been presented following

Raymer's methodology. The iterative weight sizing converges to W₀ = 14,963 kg, with We/W₀ =

0.575 and Wf/W₀ = 0.333. The aerodynamic analysis yields excellent subsonic performance:

(L/D)max = 17.0 and CD₀ = 0.00813. Three of four primary requirements are met: mission range,

sustained turn rate (14.5 deg/s), and service ceiling (far exceeded).

The Mach 2.0 requirement is not met. The Boeing X-48 geometry has a thick center body

and large planform area that generate wave drag at M = 2.0 far exceeding available afterburner

thrust. This is an inherent consequence of the chosen configuration and is reported transparently.

The design also exhibits an anomalously low wing loading (W/S = 38.9 kg/m²) arising from a scale

mismatch between the X-48 geometry and the two-seat fighter mission.

The design is internally consistent and follows Raymer's methodology rigorously. The non-

compliances identified are genuine engineering findings that inform the next design phase: center-

body area ruling, planform area reduction, or mission-profile redefinition are the primary

corrective paths forward.

REFERENCES

[1] Raymer, D. P. (2018). Aircraft Design: A Conceptual Approach, 6th ed. AIAA Education

Series, Reston, VA.

[2] Liebeck, R. H. (2004). Design of the blended wing body subsonic transport. Journal of Aircraft,

41(1), 10–25.

[3] Nickol, C. L., and McCullers, L. A. (2009). Hybrid wing body configuration system studies.

AIAA Paper 2009-931.

[4] Boeing / NASA Dryden (2013). X-48B/C Blended Wing Body Demonstrator Program. NASA

TM-2013-217549.

[5] Anderson, J. D. (2005). Introduction to Flight, 5th ed. McGraw-Hill, New York.
[6] Mattingly, J. D. (2006). Elements of Propulsion: Gas Turbines and Rockets. AIAA Education

Series.

[7] General Electric Aviation (2023). GE F110-GE-132 Military Engine Product Specification.
[8] Whitford, R. (1987). Design for Air Combat. Jane’s Information Group.
[9] Abbott, I. H., and Von Doenhoff, A. E. (1945). Summary of Airfoil Data. NACA TR-824.
[10] Torenbeek, E. (1982). Synthesis of Subsonic Aircraft Design. Delft University Press.

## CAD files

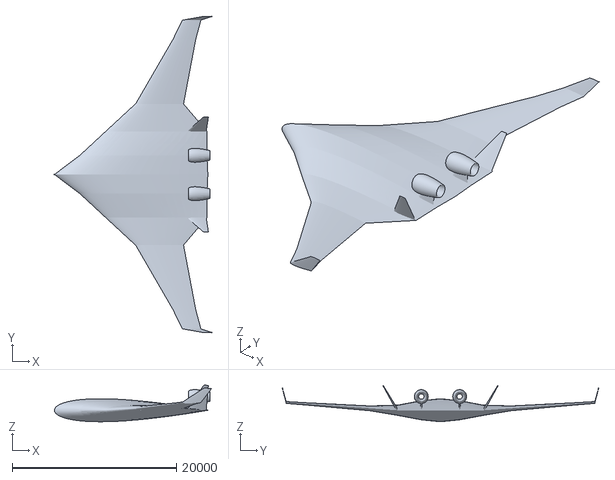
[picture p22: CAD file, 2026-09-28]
tools/cad/STL_File_Sergio_Jorge_Koutar_cfdanalysis.STL
19116.4 x 38445.5 x 4446.1

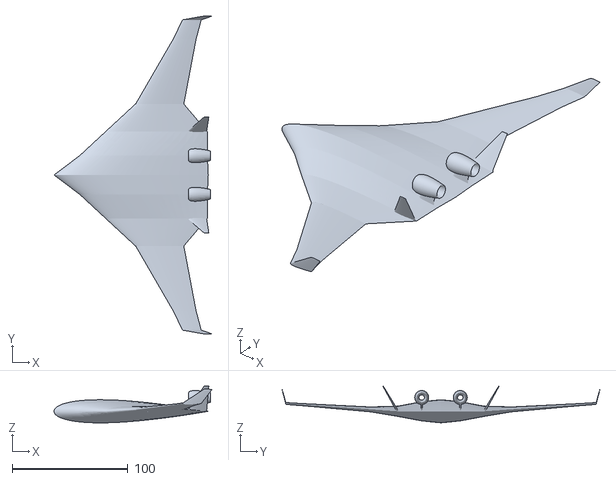
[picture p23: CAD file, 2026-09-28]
tools/cad/STL_File_Sergio_Jorge_Koutar_3dprint.STL
136.5 x 274.6 x 31.8
